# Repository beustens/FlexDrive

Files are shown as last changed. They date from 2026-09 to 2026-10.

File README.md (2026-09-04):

# FlexDrive

Simple, low-cost, yet powerful BLDC motor controller.

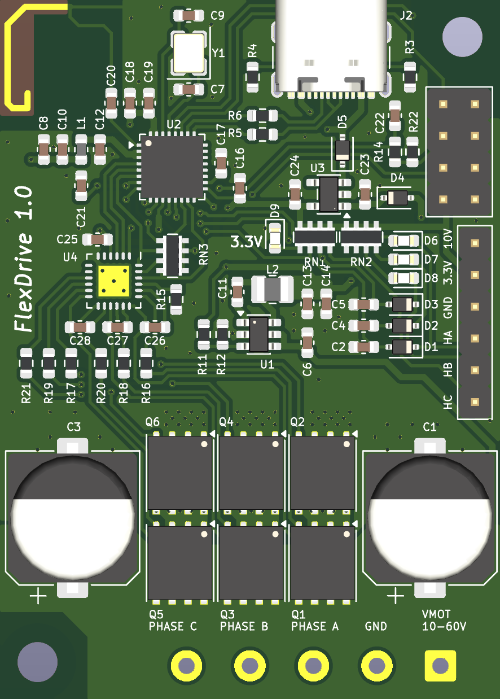
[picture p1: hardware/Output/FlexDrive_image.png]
PCB top view


## Specs and Features
- Dimensions: 40x56 mm
- Motor voltage: 10...60 V
- Peak current: 60 A (based on MOSFET specs). 20 A continous should be realistic depending on cooling
- 12 € component cost (based on 1x part prices). High volume discount could easily reduce to < 8 € per board
- Hall as default sensor input. 2 GPIOs (default UART Rx/Tx) available for other sensors
- 2-layer design for easy mods/repair (4-layer require long pre-heating to de-solder components)
- ESP32-C3 microcontroller with PCB antenna
- [SimpleFOC](https://simplefoc.com) based firmware
- Flexible control interface (therefore the name):
    - USB serial with 115200 baud using the normal SimpleFOC commands: https://docs.simplefoc.com/commander_motor
    - Analog / direction
    - RC PWM (1...2 ms pulses)
    - (Not implemented yet) wireless via ESP-Now
    - (Not implemented yet) chaining of multiple boards via UART

NOTE:
- **No current sensing** (to keep it simple and cheap). Voltage torque, velocity, angle, open and closed loop modes working though
- The GPIO pins are not 5 V tolerant! Use max 3.3 V for analog, direction / RC PWM. The hall sensor inputs can be high voltage as protected via diodes.
- 3.3 V and 10 V generated on the board are output and can be used to power the hall sensors of the motor

## Flashing the firmware
You need VSCode with the PlatformIO IDE extension installed. When the firmware directory is opened with VSCode, the extension detects the [platformio.ini](firmware/platformio.ini) and sets up everything automatically (downloads dependencies like the Arduino framework and SimpleFOC library).

NOTE: As of writing this (Sep 2026), there is an [issue](https://github.com/simplefoc/Arduino-FOC/issues/471) in the SimpleFOC library (V2.4.0) which still persists. So you have to fix it locally:
- Open *.pio/libdeps/esp32-c3-devkitm-1/Simple FOC/src/drivers/hardware_specific/esp32/esp32_ledc_mcu.cpp*
- Move `group_channels_used[group]++;` after `params->groups[...;` in the `_configure<n>PWM` functions

Connect the board with a USB-C cable to the computer and click on the upload arrow (on the bottom blue bar) in VSCode.

NOTE: The microcontroller stays in bootloader mode when only powered by USB. You need to disconnect the USB cable and first power the board with motor voltage to boot the firmware application.

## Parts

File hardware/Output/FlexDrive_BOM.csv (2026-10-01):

Reference | Qty | Value | Footprint | LCSC
C1,C3 | 2 | 150u | Capacitor_SMD:CP_Elec_10x12.5 | C28241
C2,C4,C5,C18 | 4 | 10n | Capacitor_SMD:C_0603_1608Metric | C57112
C6,C10,C11,C16,C26,C27,C28 | 7 | 100n | Capacitor_SMD:C_0603_1608Metric | C15725
C7,C9,C20 | 3 | 15p | Capacitor_SMD:C_0603_1608Metric | C1644
C8,C13,C14,C22,C23,C24 | 6 | 10u | Capacitor_SMD:C_0603_1608Metric | C96446
C12,C17,C19,C21,C25 | 5 | 1u | Capacitor_SMD:C_0603_1608Metric | C15849
D1,D2,D3,D4,D5 | 5 | PMEG4010 | Diode_SMD:D_SOD-323 | C191023
D6,D7,D8,D9 | 4 | 150060GS75000 | LED_SMD:LED_0603_1608Metric | C2286
J1 | 1 | TBC05-06-1-G-G | Connector_PinHeader_2.54mm:PinHeader_1x06_P2.54mm_Vertical
J2 | 1 | USB4105-GF-A | Connector_USB:USB_C_Receptacle_GCT_USB4105-xx-A_16P_TopMnt_Horizontal | C3020560
J4 | 1 | TB010-508-05BE | TerminalBlock_MetzConnect:TerminalBlock_MetzConnect_Type101_RT01605HBWC_1x05_P5.08mm_Horizontal
L1 | 1 | MMZ1608Y601B | Inductor_SMD:L_0603_1608Metric | C1002
L2 | 1 | LQH2HPZ4R7MJRL | Inductor_SMD:L_1008_2520Metric | C87640
Q1,Q2,Q3,Q4,Q5,Q6 | 6 | CSD18537NQ5A | Package_TO_SOT_SMD:TDSON-8-1 | C534374
R3,R4 | 2 | 5.1k | Resistor_SMD:R_0603_1608Metric | C23186
R5,R6,R16,R17,R18,R19,R20,R21 | 8 | 15R | Resistor_SMD:R_0603_1608Metric | C22810
R11,R15,R22 | 3 | 120k | Resistor_SMD:R_0603_1608Metric | C25808
R12,R14 | 2 | 10k | Resistor_SMD:R_0603_1608Metric | C25804
RN1,RN2,RN3 | 3 | TC164-JR-0710KL | Resistor_SMD:R_Array_Concave_4x0603 | C29718
U1 | 1 | LMR51606YDBVR | Package_TO_SOT_SMD:SOT-23-6 | C33545953
U2 | 1 | ESP32-C3FH4 | Package_DFN_QFN:QFN-32-1EP_5x5mm_P0.5mm_EP3.7x3.7mm | C2858491
U3 | 1 | AP2204K-3.3 | Package_TO_SOT_SMD:SOT-23-5 | C112032
U4 | 1 | DRV8300DRGER | ProjLib:VQFN_RGE0024B | C3655801
Y1 | 1 | X322540M | Crystal:Crystal_SMD_3225-4Pin_3.2x2.5mm | C252256

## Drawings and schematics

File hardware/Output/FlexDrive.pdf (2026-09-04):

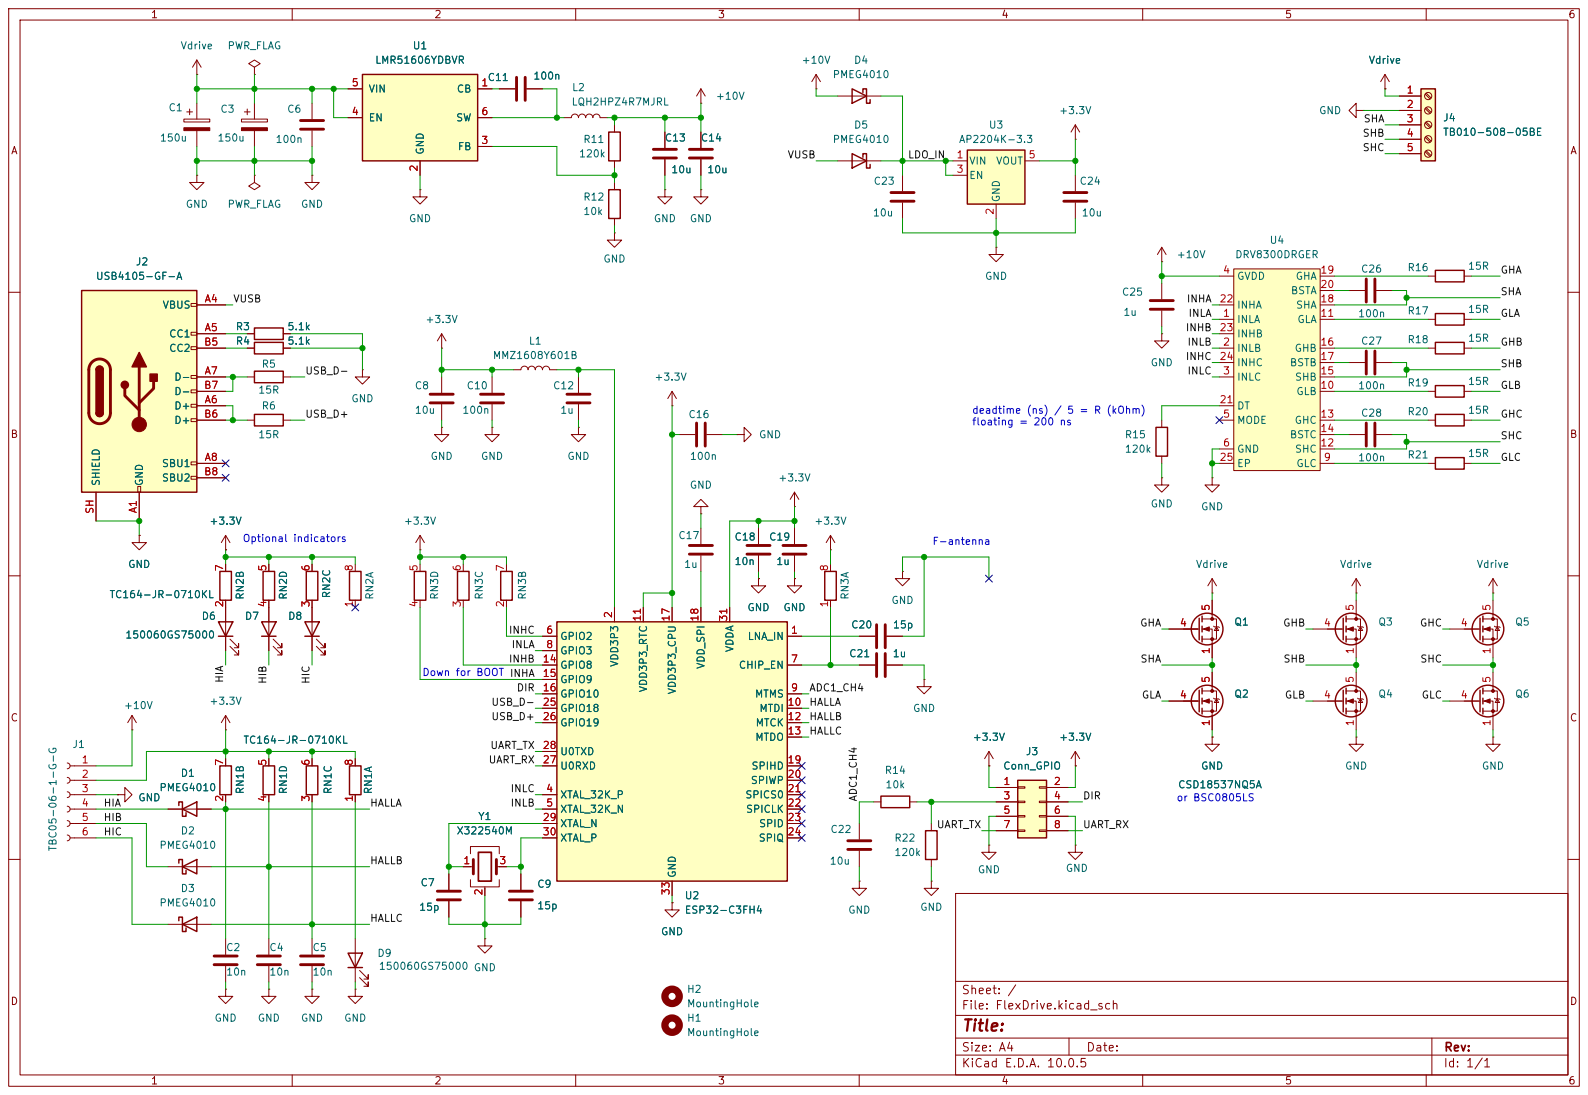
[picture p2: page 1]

SHA 18 GHA 19 BSTA 20 DT 21

Size: A4 | Rev:
KiCad E.D.A. 10.0.5 | Id: 1/1

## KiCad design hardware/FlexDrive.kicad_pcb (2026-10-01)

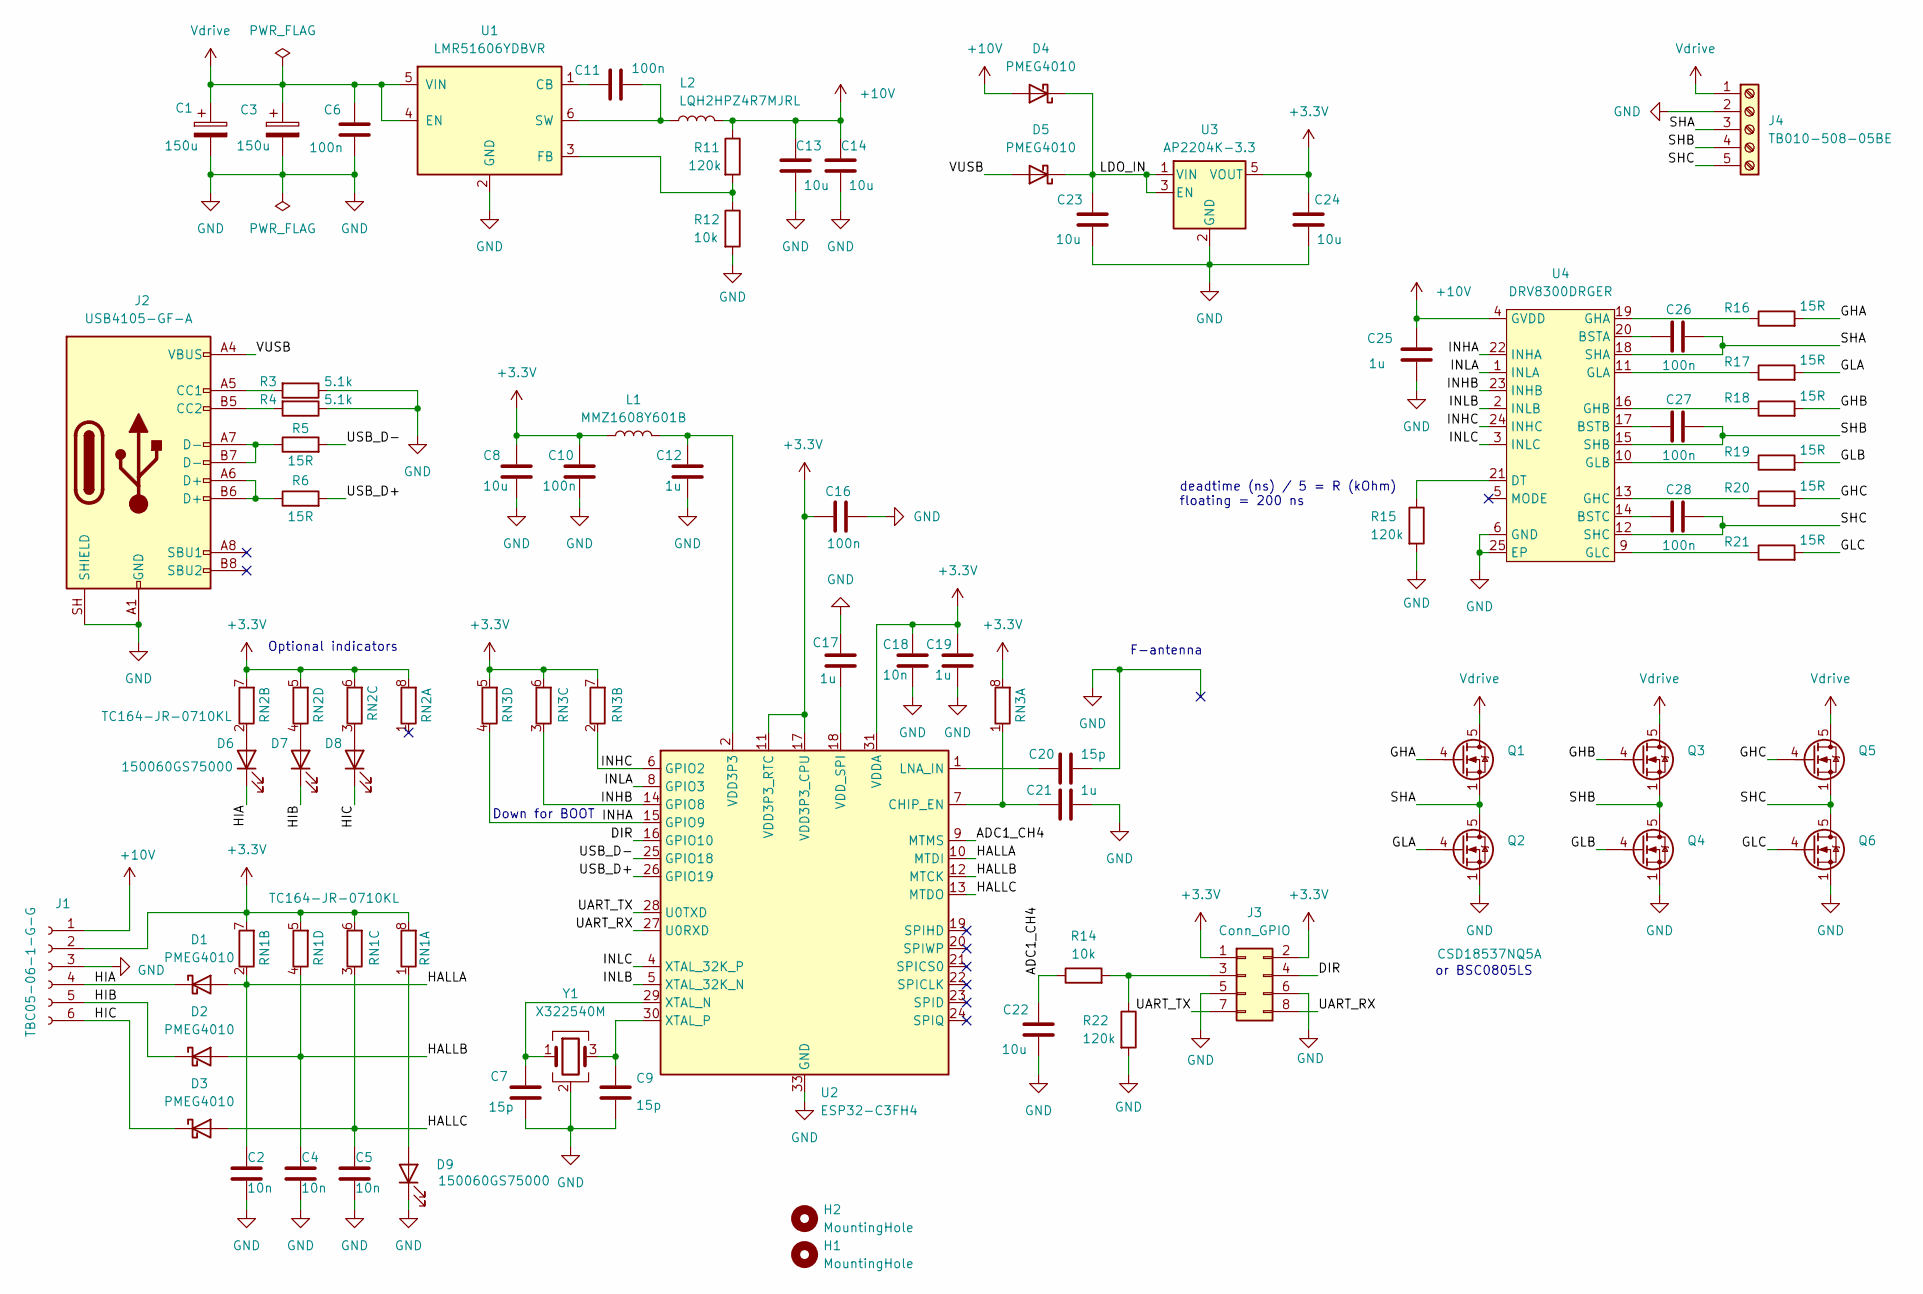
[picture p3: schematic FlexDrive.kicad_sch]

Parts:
C1, C3: 150u; CP_Elec_10x12.5; LCSC C28241
C2, C4, C5, C18: 10n; C_0603_1608Metric; LCSC C57112
C6, C10, C11, C16, C26, C27, C28: 100n; C_0603_1608Metric; LCSC C15725
C7, C9, C20: 15p; C_0603_1608Metric; LCSC C1644
C8, C13, C14, C22, C23, C24: 10u; C_0603_1608Metric; LCSC C96446
C12, C17, C19, C21, C25: 1u; C_0603_1608Metric; LCSC C15849
D1, D2, D3, D4, D5: PMEG4010; D_SOD-323; LCSC C191023
D6, D7, D8, D9: 150060GS75000; LED_0603_1608Metric; LCSC C2286
H1, H2: MountingHole; MountingHole_3.2mm_M3_DIN965
J1: TBC05-06-1-G-G; PinHeader_1x06_P2.54mm_Vertical
J2: USB4105-GF-A; USB_C_Receptacle_GCT_USB4105-xx-A_16P_TopMnt_Horizontal; LCSC C3020560
J3: Conn_GPIO; PinHeader_2x04_P2.54mm_Vertical
J4: TB010-508-05BE; TerminalBlock_MetzConnect_Type101_RT01605HBWC_1x05_P5.08mm_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
L1: MMZ1608Y601B; L_0603_1608Metric; LCSC C1002
L2: LQH2HPZ4R7MJRL; L_1008_2520Metric; LCSC C87640
Q1, Q2, Q3, Q4, Q5, Q6: CSD18537NQ5A; TDSON-8-1; LCSC C534374
R3, R4: 5.1k; R_0603_1608Metric; LCSC C23186
R5, R6, R16, R17, R18, R19, R20, R21: 15R; R_0603_1608Metric; LCSC C22810
R11, R15, R22: 120k; R_0603_1608Metric; LCSC C25808
R12, R14: 10k; R_0603_1608Metric; LCSC C25804
RN1, RN2, RN3: TC164-JR-0710KL; R_Array_Concave_4x0603; LCSC C29718
U1: LMR51606YDBVR; SOT-23-6; LCSC C33545953
U2: ESP32-C3FH4; QFN-32-1EP_5x5mm_P0.5mm_EP3.7x3.7mm; LCSC C2858491
U3: AP2204K-3.3; SOT-23-5; LCSC C112032
U4: DRV8300DRGER; VQFN_RGE0024B; LCSC C3655801
Y1: X322540M; Crystal_SMD_3225-4Pin_3.2x2.5mm; LCSC C252256

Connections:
+3.3V: C8.1, C10.1, C16.2, C18.1, C19.1, C24.2, J1.2, J3.1, J3.2, L1.1, RN1.5 (R4.2), RN1.6 (R3.2), RN1.7 (R2.2), RN1.8 (R1.2), RN2.5 (R4.2), RN2.6 (R3.2), RN2.7 (R2.2), RN2.8 (R1.2), RN3.5 (R4.2), RN3.6 (R3.2), RN3.7 (R2.2), RN3.8 (R1.2), U2.11 (VDD3P3_RTC), U2.17 (VDD3P3_CPU), U2.31 (VDDA), U2.32 (VDDA), U3.5 (VOUT)
+10V: C13.2, C14.2, C25.1, D4.2 (A), J1.1, L2.2, R11.1, U4.4 (GVDD)
/ADC1_CH4: C22.2, R14.1, U2.9 (MTMS)
/DIR: J3.4, U2.16 (GPIO10)
/GHA: Q1.4 (G), R16.2
/GHB: Q3.4 (G), R18.2
/GHC: Q5.4 (G), R20.2
/GLA: Q2.4 (G), R17.2
/GLB: Q4.4 (G), R19.2
/GLC: Q6.4 (G), R21.2
/HALLA: C2.1, D1.2 (A), RN1.2 (R2.1), U2.10 (MTDI)
/HALLB: C4.1, D2.2 (A), RN1.4 (R4.1), U2.12 (MTCK)
/HALLC: C5.1, D3.2 (A), RN1.3 (R3.1), U2.13 (MTDO)
/HIA: D1.1 (K), D6.1 (K), J1.4
/HIB: D2.1 (K), D7.1 (K), J1.5
/HIC: D3.1 (K), D8.1 (K), J1.6
/INHA: RN3.4 (R4.1), U2.15 (GPIO9), U4.22 (INHA)
/INHB: RN3.3 (R3.1), U2.14 (GPIO8), U4.23 (INHB)
/INHC: RN3.2 (R2.1), U2.6 (GPIO2), U4.24 (INHC)
/INLA: U2.8 (GPIO3), U4.1 (INLA)
/INLB: U2.5 (XTAL_32K_N), U4.2 (INLB)
/INLC: U2.4 (XTAL_32K_P), U4.3 (INLC)
/LDO_IN: C23.2, D4.1 (K), D5.1 (K), U3.1 (VIN), U3.3 (EN)
/SHA: C26.1, J4.3, Q1.1 (S), Q1.2 (S), Q1.3 (S), Q2.5 (D), U4.18 (SHA)
/SHB: C27.1, J4.4, Q3.1 (S), Q3.2 (S), Q3.3 (S), Q4.5 (D), U4.15 (SHB)
/SHC: C28.1, J4.5, Q5.1 (S), Q5.2 (S), Q5.3 (S), Q6.5 (D), U4.12 (SHC)
/UART_RX: J3.8, U2.27 (U0RXD)
/UART_TX: J3.7, U2.28 (U0TXD)
/USB_D+: R6.2, U2.26 (GPIO19)
/USB_D-: R5.2, U2.25 (GPIO18)
/VUSB: D5.2 (A), J2.A4 (VBUS), J2.A9 (VBUS), J2.B4 (VBUS), J2.B9 (VBUS)
GND: C1.2, C2.2, C3.2, C4.2, C5.2, C6.1, C7.2, C8.2, C9.2, C10.2, C12.2, C13.1, C14.1, C16.1, C17.1, C18.2, C19.2, C20.1, C21.2, C22.1, C23.1, C24.1, C25.2, D9.1 (K), J1.3, J2.A1 (GND), J2.A12 (GND), J2.B1 (GND), J2.B12 (GND), J2.SH (SHIELD), J3.5, J3.6, J4.2, Q2.1 (S), Q2.2 (S), Q2.3 (S), Q4.1 (S), Q4.2 (S), Q4.3 (S), Q6.1 (S), Q6.2 (S), Q6.3 (S), R3.1, R4.1, R12.2, R15.2, R22.2, U1.2 (GND), U2.33 (GND), U3.2 (GND), U4.6 (GND), U4.25 (EP), Y1.2 (G), Y1.4 (G)
unnamed: C12.1, L1.2, U2.2 (VDD3P3), U2.3 (VDD3P3)
unnamed: D6.2 (A), RN2.2 (R2.1)
unnamed: D7.2 (A), RN2.4 (R4.1)
unnamed: D8.2 (A), RN2.3 (R3.1)
unnamed: D9.2 (A), RN1.1 (R1.1)
unnamed: J2.A5 (CC1), R3.2
unnamed: J2.B5 (CC2), R4.2
unnamed: J2.A6 (D+), J2.B6 (D+), R6.1
unnamed: J2.A7 (D-), J2.B7 (D-), R5.1
unnamed: J3.3, R14.2, R22.1
unnamed: C21.1, RN3.1 (R1.1), U2.7 (CHIP_EN)
unnamed: C11.1, U1.1 (CB)
unnamed: R11.2, R12.1, U1.3 (FB)
unnamed: C11.2, L2.1, U1.6 (SW)
unnamed: C20.2, U2.1 (LNA_IN)
unnamed: C17.2, U2.18 (VDD_SPI)
unnamed: C7.1, U2.29 (XTAL_N), Y1.1
unnamed: C9.1, U2.30 (XTAL_P), Y1.3
unnamed: C26.2, U4.20 (BSTA)
unnamed: C27.2, U4.17 (BSTB)
unnamed: C28.2, U4.14 (BSTC)
unnamed: R15.1, U4.21 (DT)
unnamed: R16.1, U4.19 (GHA)
unnamed: R18.1, U4.16 (GHB)
unnamed: R20.1, U4.13 (GHC)
unnamed: R17.1, U4.11 (GLA)
unnamed: R19.1, U4.10 (GLB)
unnamed: R21.1, U4.9 (GLC)
Vdrive: C1.1, C3.1, C6.2, J4.1, Q1.5 (D), Q3.5 (D), Q5.5 (D), U1.4 (EN), U1.5 (VIN)

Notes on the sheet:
Optional indicators
Down for BOOT
F-antenna
or BSC0805LS
deadtime (ns) / 5 = R (kOhm) floating = 200 ns

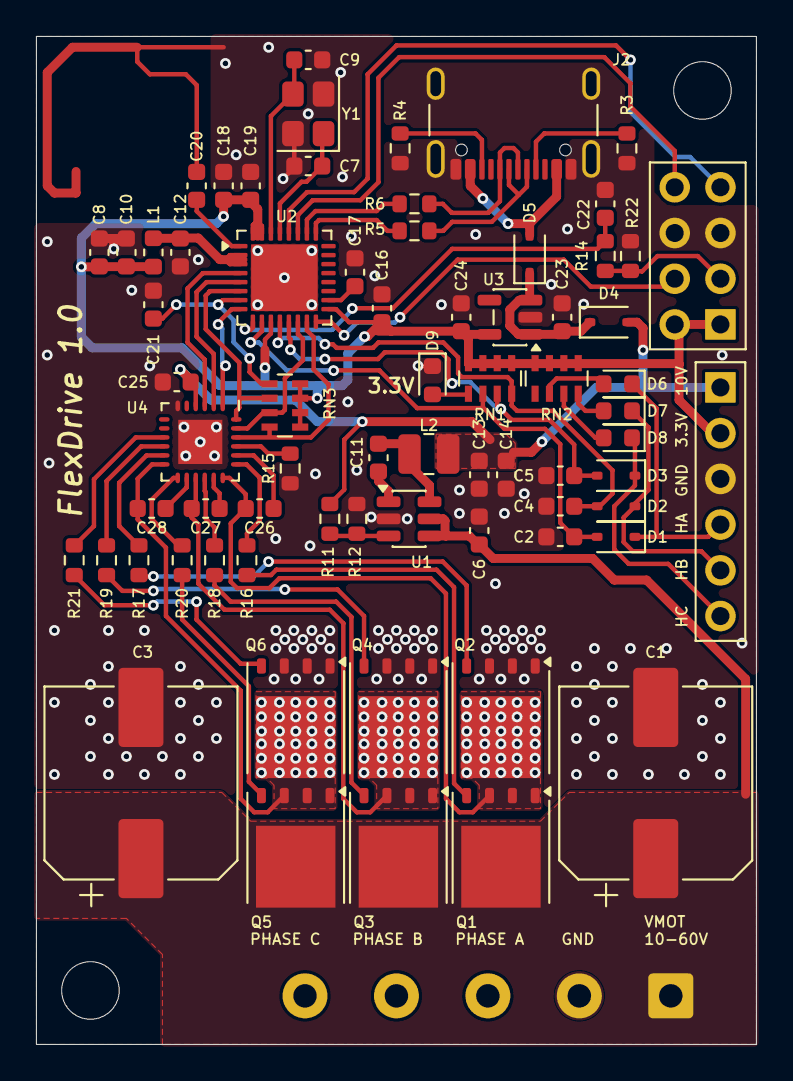
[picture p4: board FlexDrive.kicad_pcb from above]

Board: 2 copper layers, 40.0 x 56.0 mm, 73 parts (0 on the bottom side), 61 nets.

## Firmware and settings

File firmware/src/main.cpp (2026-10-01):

#include <Arduino.h>
#include <SimpleFOC.h>
#include <Preferences.h> // ESP32 non-volatile storage (NVS, in flash)

#define ADC_PIN 4
#define DIGI_PIN 10

const int defaultPolePairs = 2; // Used until a value was saved, can be changed via Commander ("P<pole pairs>\n")
const int maxPolePairs = 64; // Upper sanity limit for the Commander command

// Persistent settings (NVS)
const char* const prefsNamespace = "flexdrive";
const char* const prefsKeyPolePairs = "pp";
const float supplyVoltage = 24.0;
const float motorVoltage = 16.0; // Can be changed via Commander ("MLU<voltage>\n")

// Firmware version
typedef struct {
	uint8_t major;
	uint8_t minor;
} FWVersion;
FWVersion fwVer = {1, 1};

// Motor instance
BLDCMotor motor(defaultPolePairs);

// Driver instance
// AH, AL, BH, BL, CH, CL
/*
Important!!! Fix .pio/libdeps/esp32-c3-devkitm-1/Simple FOC/src/drivers/hardware_specific/esp32/esp32_ledc_mcu.cpp
by moving `group_channels_used[group]++;` after `params->groups[...;`
*/
BLDCDriver6PWM driver(9, 3, 8, 1, 2, 0);

// Hall sensor instance
// A, B, C, pole pairs
HallSensor sensor(5, 6, 7, defaultPolePairs);

// Change the pole pairs (better not call when motor is running!)
bool setPolePairs(int pp) {
	if (pp < 1 || pp > maxPolePairs) return false;
	if (pp == motor.pole_pairs) return true;

	// Update both users of the pole pairs together
	motor.pole_pairs = pp;
	sensor.cpr = pp * 6;

	return true;
}

// Load the saved pole pairs, falls back to the default if nothing (valid) was saved yet
int loadPolePairs() {
	Preferences prefs;
	int pp = defaultPolePairs;
	if (prefs.begin(prefsNamespace, true)) { // read-only
		pp = prefs.getUChar(prefsKeyPolePairs, defaultPolePairs);
		prefs.end();
	}
	if (pp < 1 || pp > maxPolePairs) pp = defaultPolePairs; // corrupt / out of range
	return pp;
}

// Save the pole pairs to flash, skips the write if the stored value is already identical (flash wear)
bool savePolePairs(int pp) {
	Preferences prefs;
	if (!prefs.begin(prefsNamespace, false)) return false;
	bool ok = true;
	if (prefs.getUChar(prefsKeyPolePairs, 0) != pp) {
		ok = prefs.putUChar(prefsKeyPolePairs, pp) == sizeof(uint8_t);
	}
	prefs.end();
	return ok;
}

// Commander interface
/*
E.g. setup closed loop velocity mode, spin with 10 rad/s and output current angle:
"MC1\n"
"M10\n"
"MMS0000001\n"

Pole pairs (saved to flash, restored at boot):
"P\n"  - print the current pole pairs
"P7\n"  - set 7 pole pairs
*/
Commander command(Serial);
void doTarget(char* cmd) { command.motor(&motor, cmd); }
void doPolePairs(char* cmd) {
	if (command.isSentinel(cmd[0])) {
		// Query only
		Serial.printf("Pole pairs: %d\n", motor.pole_pairs);
		return;
	}
	int pp = atoi(cmd);
	if (setPolePairs(pp)) {
		bool saved = savePolePairs(motor.pole_pairs);
		Serial.printf("Pole pairs: %d%s\n", motor.pole_pairs, saved ? " (saved)" : " (saving failed!)");
	} else {
		Serial.printf("Invalid pole pairs, allowed: 1...%d\n", maxPolePairs);
	}
}

// Analog input
const uint16_t adcThresh = 20;

// PWM pulse measurement
volatile uint32_t pulseStart = 0;
volatile uint32_t pulseWidth = 0;

void IRAM_ATTR handlePWM() {
	uint32_t currentTime = micros();

	if (digitalRead(DIGI_PIN) == HIGH) {
		// Pulse started
		pulseStart = currentTime;
	} else {
		// Pulse ended
		if (pulseStart != 0) {
			pulseWidth = currentTime - pulseStart;
		}
	}
}

void setup() {
	Serial.begin(115200);

	// GPIO
	pinMode(DIGI_PIN, INPUT_PULLUP);
	attachInterrupt(digitalPinToInterrupt(DIGI_PIN), handlePWM, CHANGE);

	// Monitor
	motor.useMonitoring(Serial);
	motor.monitor_variables = 0; // default _MON_TARGET | _MON_VOLT_Q | _MON_VEL | _MON_ANGLE
	motor.monitor_downsample = 1000; // default 10
	SimpleFOCDebug::enable(NULL); // uncomment to show details while setting up

	// Restore the saved pole pairs. The motor and sensor objects were constructed with the default,
	// and nothing is initialized yet, so both values can simply be assigned here
	int savedPolePairs = loadPolePairs();
	setPolePairs(savedPolePairs);

	// Hall Sensor setup
	// sensor.pullup = Pullup::USE_INTERN;
	sensor.init();

	// Driver & Motor setup
	driver.voltage_power_supply = supplyVoltage;
	driver.init();

	motor.torque_controller = TorqueControlType::voltage; // set the torque control type
	motor.controller = MotionControlType::torque;
	// motor.controller = MotionControlType::velocity;
	motor.updateVoltageLimit(motorVoltage); // for open loop, keep very low (2...6 V)!
	motor.voltage_sensor_align = 3.0;
	motor.velocity_limit = 20.0; // for position control
	// For closed loop operation
	motor.PID_velocity.P = 0.1;
	motor.PID_velocity.I = 0.2;
	// motor.LPF_velocity.Tf = 0.02;
	// motor.P_angle.P = 20;

	motor.linkSensor(&sensor);
	motor.linkDriver(&driver);

	motor.init();
	motor.initFOC();

	// Commander Setup
	command.add('M', doTarget, "motor control");
	command.add('P', doPolePairs, "pole pairs");

	Serial.printf("FlexDrive V%d.%d, pole pairs: %d\n", fwVer.major, fwVer.minor, motor.pole_pairs);
	Serial.println("Commands: https://docs.simplefoc.com/commander_motor");
	Serial.println("Pole pairs: P<1...64>");
}

void loop() {
	// Iterative FOC function
	motor.loopFOC();

	// Iterative function setting and calculating the angle/position loop
	// This function can be run at much lower frequency than loopFOC function
	motor.move();

	// Commander interface with the user
	command.run();

	// Output configured variable values
	motor.monitor();

	// Use hardware interface
	static uint32_t oldTime = 0;
	uint32_t newTime = millis();
	if (newTime - oldTime > 50) {
		oldTime = newTime;

		float duty;
		uint16_t adcVal = analogRead(ADC_PIN);
		if (pulseWidth >= 1000 && pulseWidth <= 2000) {
			// PWM
			duty = (static_cast<float>(pulseWidth) - 1500.0) / 500.0;
			// Serial.printf("PWM: %d\n", pulseWidth);
			motor.target = motor.voltage_limit * duty;
		} else if (adcVal >= adcThresh) {
			// Analog
			// Serial.printf("ADC: %d\n", adcVal);
			duty = static_cast<float>(adcVal - adcThresh) / (4095.0 - adcThresh);
			if (digitalRead(DIGI_PIN) == LOW) duty = -duty;
			motor.target = motor.voltage_limit * duty;
		}
	}
}
